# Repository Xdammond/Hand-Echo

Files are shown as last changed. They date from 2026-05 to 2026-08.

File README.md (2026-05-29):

# Hand Echo

## Overview
Hand Echo is a wireless robotic hand teleoperation system designed to replicate user hand movements through a sensor-equipped glove and servo-actuated robotic hand.

## Project Goals
- Capture finger motion using wearable sensors
- Transmit motion data wirelessly between microcontrollers
- Control a robotic hand in real time
- Build a modular system with separate glove, receiver, and mechanical subsystems
- Document hardware, firmware, testing, and lessons learned

## Subsystems

### Glove Controller
The glove controller measures finger movement using sensors mounted to a wearable glove. Sensor data is read by a microcontroller, processed, and prepared for wireless transmission.

### Wireless Communication
The wireless link sends motion data from the glove controller to the robotic hand receiver. This subsystem includes packet formatting, transmission timing, and reliability testing.

### Robotic Hand Receiver
The robotic hand receiver interprets incoming wireless data and controls servos to reproduce finger motion on the robotic hand.

## Repository Structure
docs/          System documentation and engineering notes
hardware/      Schematics, wiring diagrams, and BOMs
firmware/      Microcontroller code
media/         Images, videos, and diagrams
test_data/     Test results and measurements

## Status
Completed

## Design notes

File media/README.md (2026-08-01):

Videos of testing and photos of schematics
This folder contains pictures and videos of testing and schematic design throughout the 14 weeks of testing and troubleshoot

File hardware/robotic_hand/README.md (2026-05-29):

# Robotic Hand

Contains:

- Servo configuration
- Mechanical assembly
- Wiring information

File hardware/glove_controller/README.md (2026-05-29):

# Glove Controller

Contains:

- Sensor information
- Wiring diagrams
- Schematics
- Calibration data

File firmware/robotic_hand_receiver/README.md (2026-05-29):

# Robotic Hand Receiver Firmware

Firmware responsible for:

- Receiving wireless packets
- Mapping data to servos
- Motion control

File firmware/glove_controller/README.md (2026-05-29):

# Glove Controller Firmware

Firmware responsible for:

- Reading sensors
- Processing motion data
- Wireless transmission

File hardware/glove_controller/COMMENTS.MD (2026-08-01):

In file R433A, our original understanding when we first purchased the component was 2 port SAW resonator. As we were testing, we began to see destabilization and oscillation dying. Without a wiring diagram for the part, we asked our professors and they all agreed that it was a two port. We then recreated a two-port system of the Colpitts oscillator but effectively it did not behave like a normal Colpitts Oscillator. It was only till March 15th, 2026, did we discover the true schematic of the component we had and then reworked the circuit back to a one-port design to have stability and ringing. 

The 2N5770 was not the intended BJT nor component we truly wanted to use. But due to our budget, we stuck with the RF BJT because it helped stabilize the circuit and allowed for the proper gain.

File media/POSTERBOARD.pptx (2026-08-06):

## Hand Echo

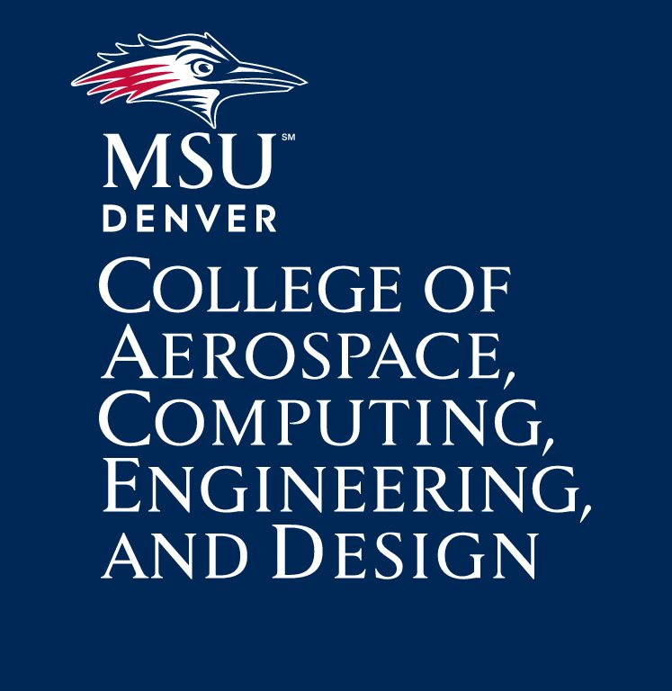
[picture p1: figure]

Student Names: Andres Arcila, John Garcia, Xavier Dammond

Email: arcila.ad23@gmail.com , johngarcia8018@gmail.com , xdammond@gmail.com

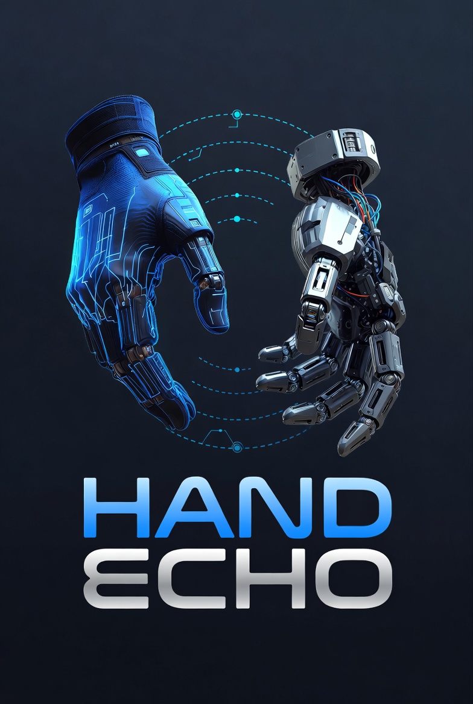
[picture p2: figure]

Conclusion

Advised by: Ke Bao

Email: kbao@msudenver.edu

Intro

Hand Echo is a wireless tele-operation system designed for real-time replication of human hand movements in environments where direct manual interaction is unsafe or impossible. The system integrates a flex-sensor-equipped glove, a custom 433.92 MHz ASK-modulated RF link, and a servo-driven robotic hand to translate finger articulation into precise mechanical motion, enabling safe operation in hazardous settings and supporting prosthetic research and development

Design

Hand Echo is a wireless teleoperation platform engineered to replicate human hand motion on a remote robotic end-effector in real time. Its architecture centers on a two-microcontroller topology — an Arduino Nano on the transmitter side and a Arduino Uno on the receiver side — linked by a 433.92 MHz ASK-modulated RF channel built around a SAW resonator and a custom Colpitts oscillator. Hand Echo integrates five flex sensors arranged in voltage-divider networks and consolidated through a 74HC4051 8-channel multiplexer, producing high-resolution finger-articulation data that is encoded, transmitted over custom-built antennas, and decoded at the receiver. A PCA9685 16-channel PWM driver communicates with the Uno over I²C to drive five servo motors actuating the robotic hand, while onboard firmware maps sensor input to servo position to maintain responsive, low-latency mirroring with minimal operator calibration. Designed for wireless range, modular sensor-to-servo mapping, and reconfigurable control logic, Hand Echo provides a robust foundation for hazardous-environment manipulation and prosthetic research applications.

Materials and methods

Arduino Nano: Microcontroller used on the transmitter (glove) side to read multiplexed flex sensor data and drive the RF transmitter.
Arduino Uno: Microcontroller used on the receiver (hand) side to decode the incoming RF signal and generate servo commands.
Flex Sensors (10 kΩ): Five resistive bend sensors, one per finger, used to measure finger articulation via voltage-divider circuits.
74HC4051 8-Channel Multiplexer: Used to sequentially route all five flex sensor outputs into a single ADC input on the Arduino Nano.
SAW Resonator (433.92 MHz): Surface acoustic wave resonator used as the frequency-reference element for the custom Colpitts oscillator transmitter.
Colpitts Oscillator Transmitter Circuit: Custom-built RF transmitter using ASK (Amplitude Shift Keying) modulation at 433.92 MHz.
RF Receiver Module: Paired 433.92 MHz receiver used to demodulate the ASK signal and forward serial data to the Arduino Uno.
PCA9685 16-Channel PWM Driver: I²C-controlled PWM controller used to generate precise servo signals for all five fingers from the Arduino Uno (SDA on pin 6, SCL on pin 7).
5V Power Supply: Powers the glove-side voltage dividers, multiplexer, and Arduino Nano.
3.7 V Li-Po Battery + 5 V Boost Converter: Portable power supply for the wireless glove assembly.
Robotic Hand with 5 Servo Motors: Mechanical end-effector actuated by the PCA9685 to mirror the operator's finger movements.

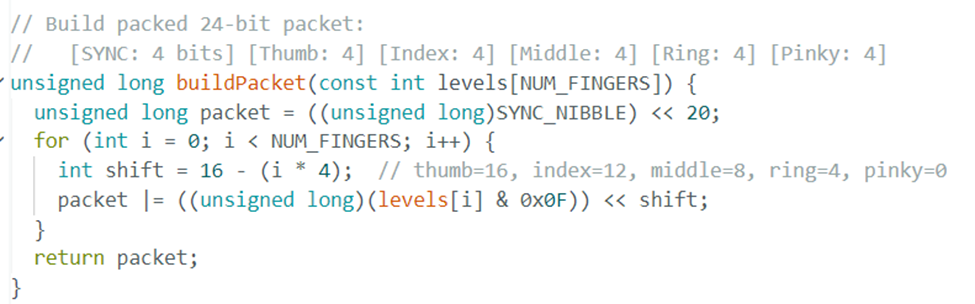
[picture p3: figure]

Results

Hand Echo Systems:

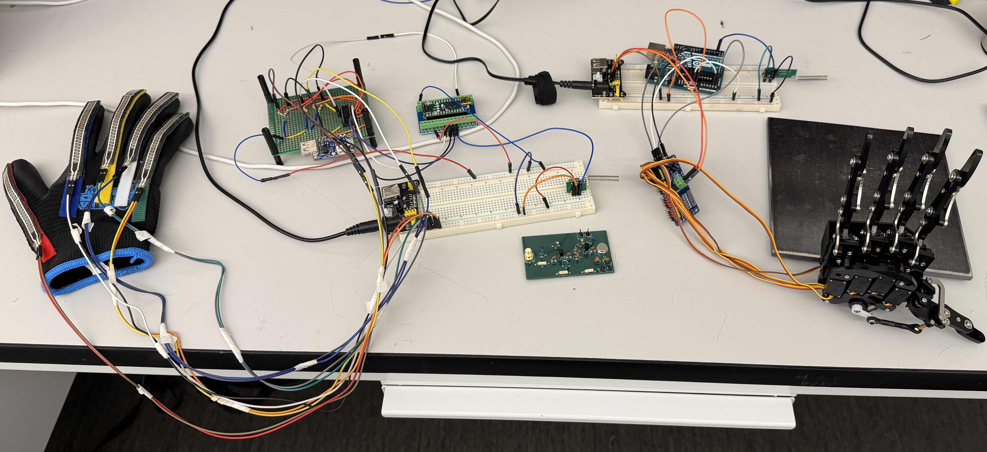
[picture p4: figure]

The Hand Echo wireless teleoperation system successfully demonstrated a functional prototype capable of capturing human finger articulation and mirroring it on a remote robotic hand in real time. Through integrated flex-sensor acquisition, a custom-built 433.92 MHz ASK-modulated RF link, and a PCA9685-driven servo actuator architecture, the system translated operator hand movements into responsive mechanical motion and validated the core design principles of the project. While the prototype met all primary objectives, opportunities remain for refinement and expansion, including resolving the servo snap-back behavior observed during initial testing, improving RF link range and noise immunity, adding bidirectional haptic feedback, expanding the sensor set to capture wrist and individual joint angles, and packaging the glove and hand assemblies into more ergonomic, field-ready enclosures. Overall, Hand Echo provides a strong foundation for a scalable, next-generation platform suited to hazardous-environment manipulation and prosthetic research applications

[1] Pozar, D. M. (2012). Microwave engineering (4th ed.). Wiley.
[2]

Acknowledgements

The group would like to give a special thanks to all of the professors, Lab Coordinators, and student lab assistants at Metropolitan State University of Denver. Without their technical and logistical support and advice this project would not have been possible.

Colpitts Oscillator Transmitter Circuit:

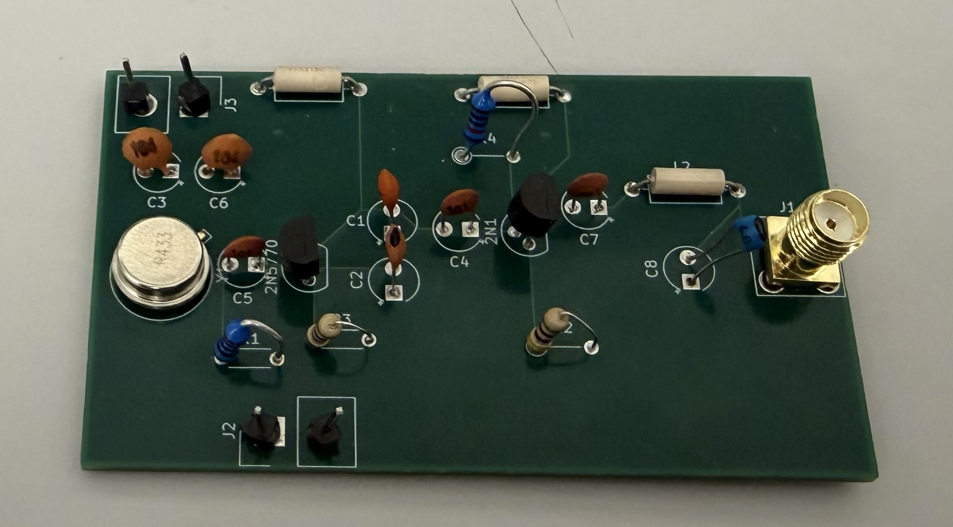
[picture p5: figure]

Code Bit-Packed Protocol

Literature Cited

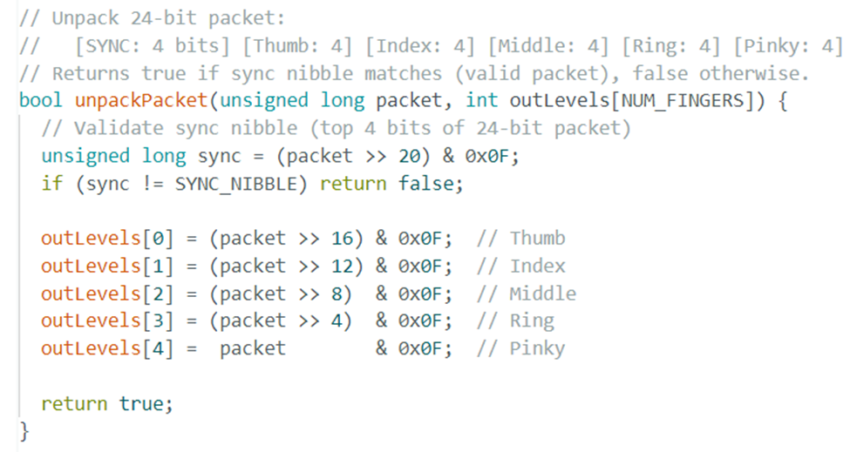
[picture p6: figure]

Waveform

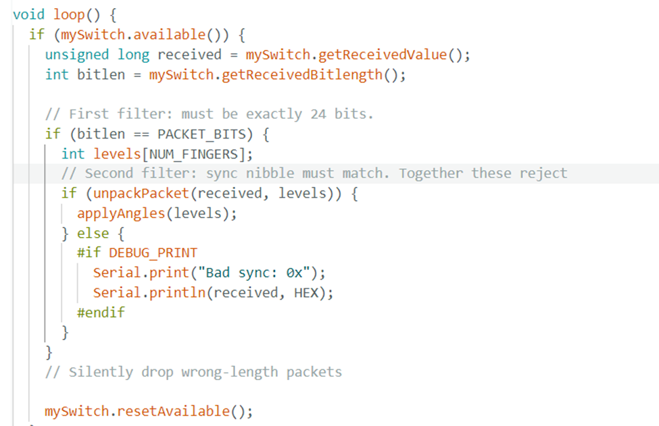
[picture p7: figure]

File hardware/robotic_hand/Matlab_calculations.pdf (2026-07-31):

Contents

John Garcia, Andres Arcilia, Xavier Dammond

%%Senior Project 1

John Garcia, Andres Arcilia, Xavier Dammond

clc; clear;

% ====== Define Average Link Lengths (mm) ======
L1 = 45; % Proximal phalanx: These are the average lengths for a nor %human hand and not our hands.
L2 = 25; % Middle phalanx
L3 = 20; % Distal phalanx
L4 = 15; % Extra flexion for ring/pinky

% ====== Target Fingertip Positions (mm) ====== fingers = {'Thumb','Index','Middle','Ring','Pinky'}; targets = [ 60 20;
70 10;
80 15;
75 5;
65 0];

% ====== Results ======
angle_results = cell(length(fingers), 5);

for i = 1:length(fingers)
finger = fingers{i};
x = targets(i, 1);
y = targets(i, 2);

% Combine L2 + L3 for effective 2R solution Leff1 = L1;
Leff2 = L2 + L3;

% Inverse Kinematics
r2 = x^2 + y^2;
cos_theta2 = (r2 - Leff1^2 - Leff2^2) / (2 * Leff1 * Leff2); cos_theta2 = max(min(cos_theta2, 1), -1); % Clamp to [-1, 1]
theta2 = acos(cos_theta2); | % In radians

k1 = Leff1 + Leff2 * cos(theta2);
k2 = Leff2 * sin(theta2);
theta1 = atan2(y, x) - atan2(k2, k1); | % In radians

% DIP joint estimate (proportional to PIP)
theta3 = theta2 * (20/45); | % Simplified approximation

% Convert to degrees
theta1_deg = rad2deg(theta1);
theta2_deg = rad2deg(theta2);
theta3_deg = rad2deg(theta3);

% For ring and pinky, add a 4th joint estimate
if strcmp(finger, 'Ring') || strcmp(finger, 'Pinky') theta4_deg = 20; % Fixed curl or tendon pull else
theta4_deg = NaN;
end

% Store results
angle_results{i,1} = finger; angle_results{i,2} = round(theta1_deg, 2); angle_results{i,3} = round(theta2_deg, 2); angle_results{i,4} = round(theta3_deg, 2); angle_results{i,5} = round(theta4_deg, 2);
end

% ====== Display Table ======
T = cell2table(angle_results, 'VariableNames', {'Finger','θ1_deg','θ2_deg','θ3_deg','θ4_deg'}); disp(T);
Finger | θ1_deg | θ2_deg | θ3_deg | θ4_deg
__________ | ______ | ______ | ______ | ______
{'Thumb' } | -26.92 | 90.71 | 40.31 | NaN
{'Index' } | -30.09 | 76.43 | 33.97 | NaN
{'Middle'} | -14.64 | 50.52 | 22.45 | NaN
{'Ring' } | -29.55 | 66.73 | 29.66 | 20
{'Pinky' } | -43.76 | 87.52 | 38.9 | 20

Published with MATLAB® R2022b (https://www.mathworks.com/products/matlab/)

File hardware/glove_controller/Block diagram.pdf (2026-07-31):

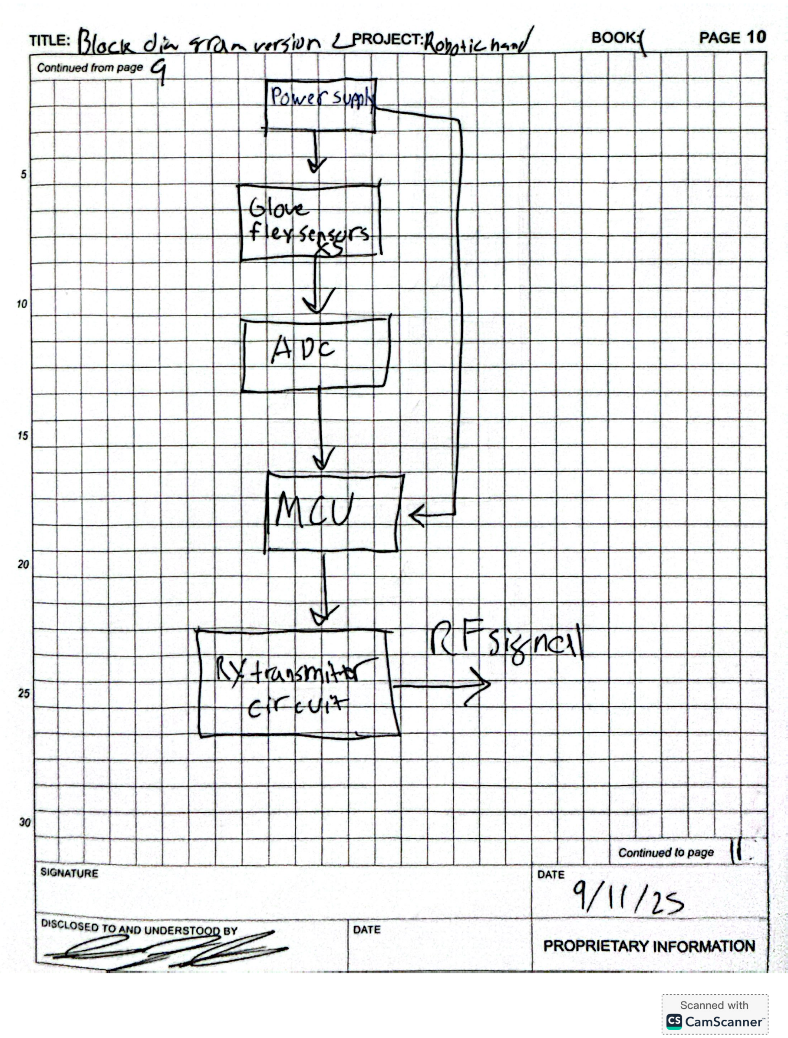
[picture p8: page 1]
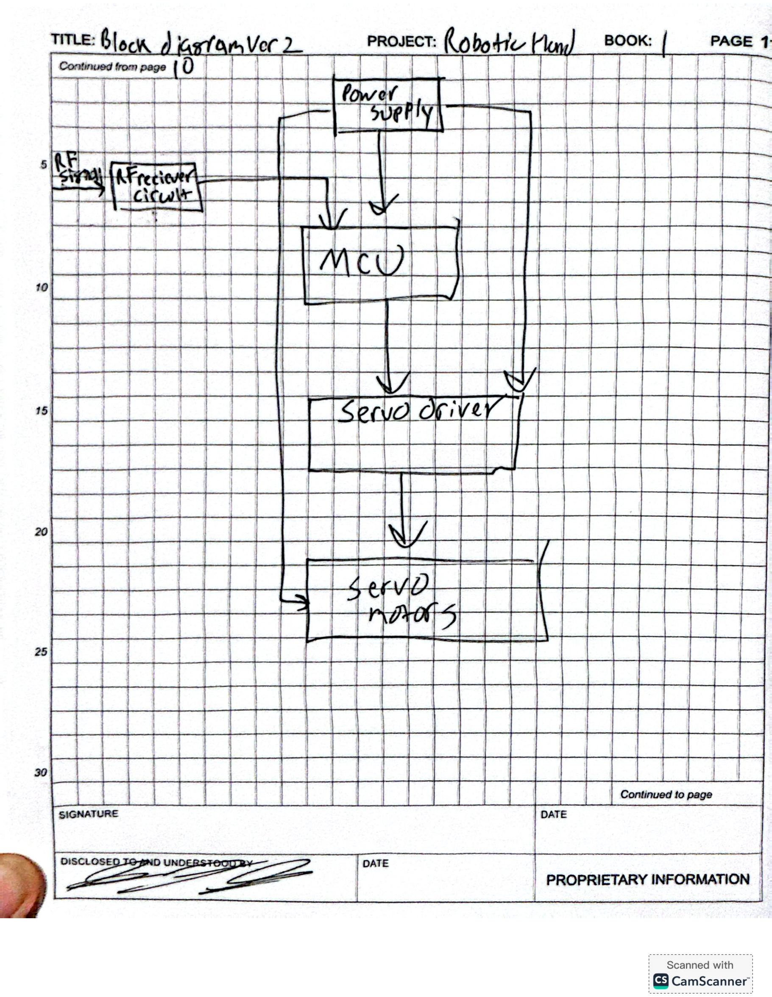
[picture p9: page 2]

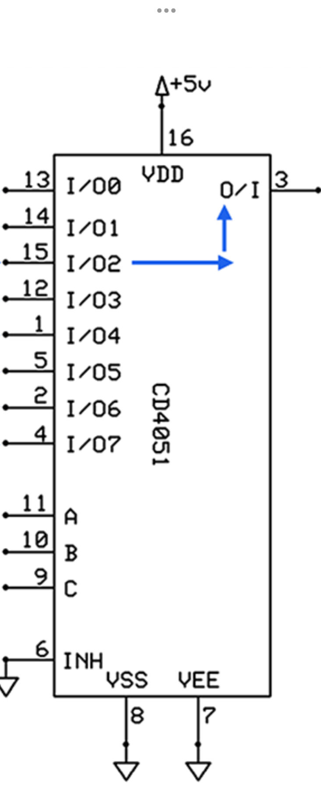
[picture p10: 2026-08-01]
hardware/glove_controller/74HC4051.jpg

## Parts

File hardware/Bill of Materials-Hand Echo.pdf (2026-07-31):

Received | 22
Received | 21
Received | 20
Received | 19
Received | 18
Received | 17
Received | 16
Received | 15
Received | 14
Received | 13
Received | 12
Received | 11
Received | 10
Received | 9
Received | 8
Received | 7
Received | 6
Received | 5
Received | 4
Received | 3 | 5pcs 433mhz Wireless RF Transmitter and Receiver with Antenna Ask Remote Control Module DIY Kit for Arduino
Received | 1
Received | 2 | HiLetgo 2pcs PCA9685 16 Channel 12-Bit PWM Servo Motor Driver IIC Module for Arduino Robot
Status | Find Number

Received
Received

23
24

Not Purchased

Received | 25
Received | 26
Received | 27
Received | 28
Not Purchased | 29
Not Purchased | 30
Not Purchased | 31
Not Purchased | 32
Not Purchased | 33
Not Purchased | 34
Not Purchased | 35
Not Purchased | 36
Not Purchased | 37
Not Purchased | 38

Statuses
Not Purchased
Purchased
Received
Cancelled

22nH Inductor

15pF Capacitor

7.5pF Capacitor

Copper Clad boards

Sma connectors

2n7000-G

100nH Inductors

0.1uH inductors

0.033uH Inductors
0.047uH Inductors

0.27uH Inductors

2N5770

433MHz Transreceiver

7pF Capacitor

68nH Inductor

27nH Inductor

PowerBoost 1000 Charger- Rechargeable 5V Lipo USB Boost @1A-1000c

Lithium Ion Polymer battery-3.7V 500mAh

Arduino Nano

5pcs 433mhz Wireless RF Transmitter and Receiver with Antenna Ask Remote Control Module DIY Kit for Arduino

Robot Hand Five Fingers Solely Movement Bionic Robot Mechanical Arm DIY, Right Hand

HiLetgo 2pcs PCA9685 16 Channel 12-Bit PWM Servo Motor Driver IIC Module for Arduino Robot

# Purchase Requests

Description

# Hand Echo

33k ohm chip resistor
100k ohm chip resistor

100pF capacitor
100nF capacitor

22pF capacitor

150 ohm chip resistor

$0.09 | 25 | $2.20 (https://www.mouser.com/ProductDetail/Murata-Electronics/LQW2BAS27NJ00L?qs=XY81OjNnpanytpCHSD7Xvg%3D%3D) | Mouser (https://www.mouser.com/ProductDetail/Murata-Electronics/LQW2BAS27NJ00L?qs=XY81OjNnpanytpCHSD7Xvg%3D%3D)
$0.19 | 25 | $4.83 | Mouser (https://www.mouser.com/ProductDetail/Murata-Electronics/LQW15AW68NG80D?qs=B6kkDfuK7%2FDzrzt3MYe9Zg%3D%3D)
$0.28 | 5 | $1.40 | Newark (https://www.newark.com/tdk/fg28c0g2a070dnt00/cap-7pf-100v-mlcc-radial-rohs/dp/70AK2660)
$9.99 | 1 | $9.99 | Amazon
$0.31 | 10 | $3.10 | DigiKey (https://www.digikey.com/en/products/detail/central-semiconductor-corp/2N5770-PBFREE/4806922)
$3.79 | 10 | $37.90 | DigiKey
$3.03 | 5 | $15.15 | DigiKey
$3.79 | 5 | $18.95 | DigiKey
$0.26 | 5 | $1.30 | DigiKey
$1.05 | 5 | $5.25 | DigiKey
$0.50 | 10 | $5.00 | DigiKey
$10.99 | 1 | $10.99 | amazon (https://www.amazon.com/bnafes-Straight-Connector-Coaxial-Adapter/dp/B09N1RBBFX)
$6.99 | 1 | $6.99 | amazon
$0.08 | 10 | $0.80 | Digikey (https://www.digikey.com/en/products/detail/murata-electronics/GJM1555C1H7R5WB01D/2593133)
$0.07 | 10 | $0.65 | Digikey (https://www.digikey.com/en/products/detail/murata-electronics/GJM1555C1H150GB01D/2592856)
$0.12 | 10 | $1.24 | DigiKey (https://www.digikey.com/en/products/detail/murata-electronics/LQW2BASR22J00L/2625454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)
$0.00 | 10 | $0.04 | DigiKey (https://www.digikey.com/en/products/detail/yageo/RC0402FR-0733KL/726592)
$0.00 | 10 | $0.04 | DigiKey (https://www.digikey.com/en/products/detail/yageo/RC0402FR-07100KL/726526)
| | | Adafruit | https://www.adafruit.com/product/1578
$19.95 | 1 | $19.95 | Adafruit | https://www.adafruit.com/product/2465
$99.00 | 1 | $99.00 | Amazon
$13.00 | 1 | $13.00 | Amazon (https://www.amazon.com/HiLetgo-PCA9685-Channel-12-Bit-Arduino/dp/B07BRS249H)
$9.99 | 1 | $9.99 (https://www.amazon.com/D-FLIFE-Wireless-Transmitter-Receiver-Antenna/dp/B0BZRRBBNK) | Amazon (https://www.amazon.com/D-FLIFE-Wireless-Transmitter-Receiver-Antenna/dp/B0BZRRBBNK)
$24.99 | 1 | $24.99 | Amazon (https://www.amazon.com/Arduino-A000005-ARDUINO-Nano/dp/B0097AU5OU?sp_csd=d2lkZ2V0TmFtZT1zcF9hdGY)
$7.95 | 1 | $7.95

Movement-Bionic-Mechanical-DIY%EF%BC%88Right/dp/B081RR42 (https://www.amazon.com/Fingers-Movement-Bionic-Mechanical-DIY%EF%BC%88Right/dp/B081RR4224?th=1)

# Purchase Requests

Unit Cost | Quanity | Cost | Supplier | Where to Buy Links

# Hand Echo

Total | 204 | $303.92
$0.20 | 10 | $2.00 | DigiKey (https://www.digikey.com/en/products/detail/yageo/RC0402FR-07150RL/726543)
$0.07 | 10 | $0.69 | DigiKey (https://www.digikey.com/en/products/detail/murata-electronics/GJM1555C1H220FB01D/7362929)
$0.01 | 10 | $0.14 | DigiKey (https://www.digikey.com/en/products/detail/murata-electronics/GRM1885C1H101JA01D/586921)
$0.04 | 10 | $0.39 | DigiKey (https://www.digikey.com/en/products/detail/samsung-electro-mechanics/CL05B104KP5VPNC/20498482)

Movement-Bionic-Mechanical-

Where to Buy Links

| Approvals
POC | Teammate

24?th=1

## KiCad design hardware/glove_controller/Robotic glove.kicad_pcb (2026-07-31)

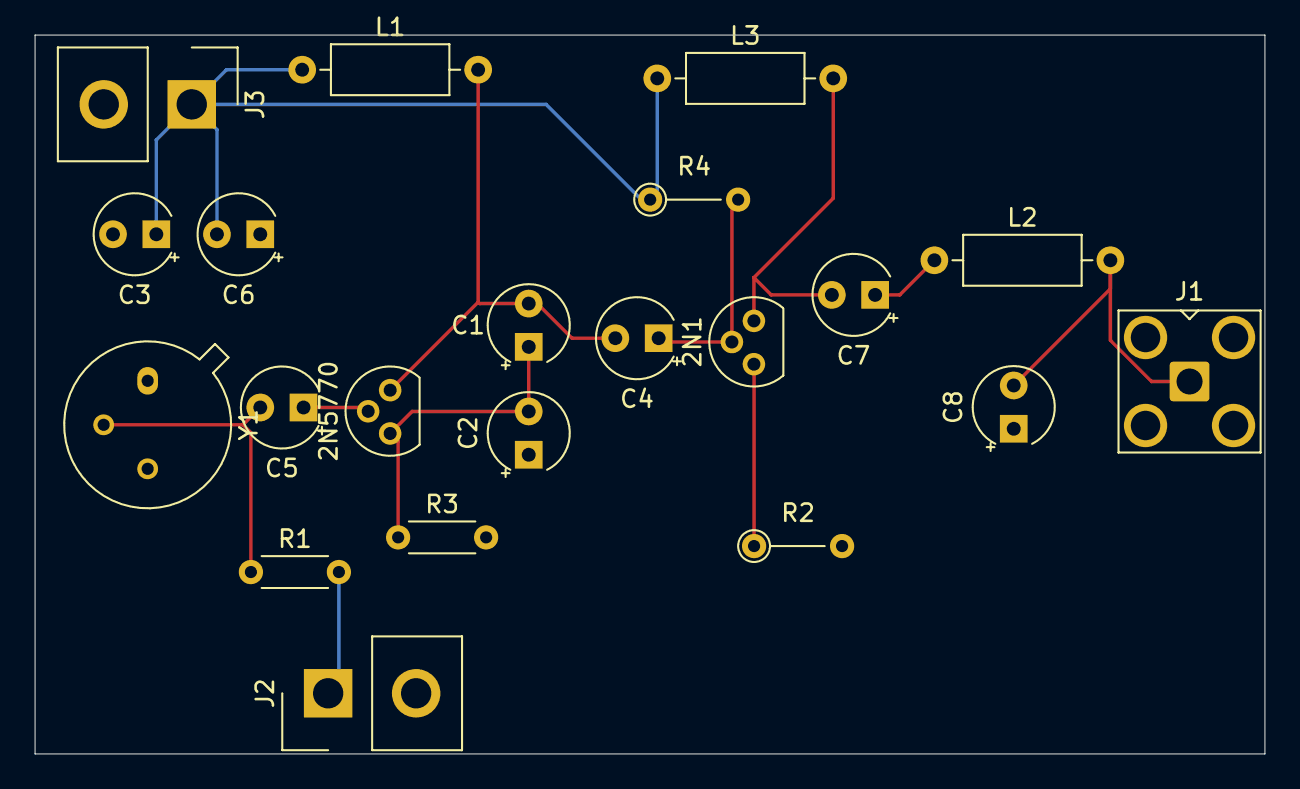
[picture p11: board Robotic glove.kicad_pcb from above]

Board: 4 copper layers, 71.0 x 41.5 mm, 21 parts (0 on the bottom side), 12 nets.

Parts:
2N1, 2N5770: Q_NPN_CBE; TO-92L
C1: 7.5pF; CP_Radial_Tantal_D4.5mm_P2.50mm
C2: 15pF; CP_Radial_Tantal_D4.5mm_P2.50mm
C3, C6: 100nF; CP_Radial_Tantal_D4.5mm_P2.50mm
C4: 10pF; CP_Radial_Tantal_D4.5mm_P2.50mm
C5, C7: 100pF; CP_Radial_Tantal_D4.5mm_P2.50mm
C8: 22pF; CP_Radial_Tantal_D4.5mm_P2.50mm
J1: 132134-15; SMA_Amphenol_901-143_Horizontal
J2, J3: Conn_01x02; Samtec_HPM-02-05-x-S_Straight_1x02_Pitch5.08mm
L1, L3: 27nH; L_Axial_L6.6mm_D2.7mm_P10.16mm_Horizontal_Vishay_IM-2
L2: 23nH; L_Axial_L6.6mm_D2.7mm_P10.16mm_Horizontal_Vishay_IM-2
R1: 33k; R_Axial_DIN0204_L3.6mm_D1.6mm_P5.08mm_Horizontal
R2, R4: 100; R_Axial_DIN0204_L3.6mm_D1.6mm_P5.08mm_Vertical
R3: 68; R_Axial_DIN0204_L3.6mm_D1.6mm_P5.08mm_Horizontal
Y1: Crystal_GND3; TO-39-3

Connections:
+5V: C3.1, C6.2, J3.1, L1.1, L3.1, R4.1
/Arduino TX in: J2.1, R1.2
Earth: C2.1, C3.2, C6.1, C8.1, J1.2, J2.2, J3.2, R2.2, R3.2, Y1.1, Y1.3
unnamed: 2N1.2 (B), C4.1, R4.2
unnamed: 2N1.1 (C), C7.2, L3.2
unnamed: 2N1.3 (E), R2.1
unnamed: 2N5770.2 (B), C5.1
unnamed: 2N5770.1 (C), C1.2, C4.2, L1.2
unnamed: 2N5770.3 (E), C1.1, C2.2, R3.1
unnamed: C5.2, R1.1, Y1.2
unnamed: C7.1, L2.1
unnamed: C8.2, J1.1, L2.2

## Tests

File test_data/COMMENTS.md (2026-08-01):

Our first test of the circuit came from analyzing an oscilloscope signal we had obtained. At first, we wondered why there was no oscillation and figured our circuit design was bad. As we moved through the weeks, it came to our attention that oscilloscope we were working with did not read up 400MHz and was effectively capped at 150MHz for a reading. We also discovered that using a bread board at 200MHz and above causes distortion inside the signal making what we were testing incorrect and data invaluable.

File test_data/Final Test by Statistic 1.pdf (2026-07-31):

## Final Test by Statistic

By: Andres Arcilia, Xavier Dammond, John Garcia

Introduction

The final test by statistics will measure 1’s and 0’s and voltage based on the keying of the transmitter of the flex sensors and the signal transmitted to the receiver module and is decoded.

Measurements/Calculations

Trial | TX volt | RX Volt
1 | 5V | 0V
2 | 3.3V | 0V
3 | 0V | 0V
4 | 5V | 3.3V
5 | 4.2V | 3.3V
6 | 5V | 5V
7 | 3.3V | 1.7V
8 | 0V | 0V
9 | 4.2V | 0V
10 | 0V | 0V
Mean TX | 3.25V
Range TX | 5V
Std Dev TX | 2.07V
Mean RX | 1.33V
Range RX | 5V
Std Dev RX | 1.789V

Analysis and Conclusion

Analysis of the TX and RX voltage data reveals that there is a decoding reliability issue within the receiver module. Even though the transmitter was able to consistently output the expected voltage levels in response to the flex sensor inputs, the receiver module failed to mirror the values within the same consistency. This could point to bit drop errors during signal decoding, which could be caused by timing mismatch, protocol not engaging properly or insufficient signal strength.

0

1

2

3

4

5

6

1 | 2 | 3 | 4 | 5 | 6 | 7 | 8 | 9 | 10

TX VS RX Voltage

TX Volts RX Volts

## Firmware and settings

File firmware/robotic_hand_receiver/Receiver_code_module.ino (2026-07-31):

/*
 * Wireless Robotic Glove - RECEIVER
 * Arduino Uno + PCA9685 + 5x LFD-01 Servos
 *
 * Protocol: 24-bit packet, bit-packed (matches transmitter exactly)
 *   [SYNC: 4 bits = 0xA] [Thumb: 4] [Index: 4] [Middle: 4] [Ring: 4] [Pinky: 4]
 *   Each finger: 0-15 (16 levels)
 *   Sync nibble validation rejects ~94% of random noise.
 *
 * Wiring:
 * --- 433MHz Receiver ---
 * DATA -> D2 (interrupt 0)
 * VCC  -> 5V
 * GND  -> GND
 *   17.3cm antenna wire on RX module ANT pad
 *
 * --- PCA9685 (I2C) ---
 * VCC -> 5V, GND -> GND, SDA -> A4, SCL -> A5
 * V+  -> External 5V (servo power, separate from logic if possible)
 *
 * --- Servos on PCA9685 ---
 * CH0 -> Thumb, CH1 -> Index, CH2 -> Middle, CH3 -> Ring, CH4 -> Pinky
 */

#include <RCSwitch.h>
#include <Wire.h>
#include <Adafruit_PWMServoDriver.h>

RCSwitch mySwitch = RCSwitch();
Adafruit_PWMServoDriver pca = Adafruit_PWMServoDriver(0x40);

// --- Servo timing ---
// 600-2400us avoids hitting hard stops on most hobby servos. Wider ranges
// cause stall current and supply noise that can deafen the 433MHz receiver.
#define SERVO_MIN_PULSE  600
#define SERVO_MAX_PULSE  2400
#define PCA_FREQ         50

// --- Protocol (must match transmitter exactly) ---
#define NUM_FINGERS       5
#define PACKET_BITS       24
#define SYNC_NIBBLE       0xA
#define LEVELS_PER_FINGER 16
#define MAX_LEVEL         15

// --- Smoothing ---
#define SMOOTH_FACTOR    0.40f

// Precomputed PWM tick conversion: at 50Hz, 4096 ticks per 20000us period.
// tick = (us * 4096 * PCA_FREQ) / 1,000,000 — pure integer math.
#define US_TO_TICK(us)   ((int)(((long)(us) * 4096L * PCA_FREQ) / 1000000L))

const int servoChannel[NUM_FINGERS] = { 0, 1, 2, 3, 4 };

const char* fingerName[NUM_FINGERS] = {
  "Thumb", "Index", "Middle", "Ring", "Pinky"
};

// Mechanical inversion: thumb is mounted opposite the other fingers in this
// hand assembly, so its servo direction is not inverted while the other four
// are. Update this array if you swap or remount any servos.
const bool invertFinger[NUM_FINGERS] = {
  false,  // Thumb
  true,   // Index
  true,   // Middle
  true,   // Ring
  true    // Pinky
};

float smoothedAngle[NUM_FINGERS] = { 0, 0, 0, 0, 0 };
bool firstPacket = true;

#define DEBUG_PRINT 1

void setServoAngle(int channel, int angle) {
  angle = constrain(angle, 0, 180);
  int pulseUs = map(angle, 0, 180, SERVO_MIN_PULSE, SERVO_MAX_PULSE);
  pca.setPWM(channel, 0, US_TO_TICK(pulseUs));
}

// Unpack 24-bit packet:
//   [SYNC: 4 bits] [Thumb: 4] [Index: 4] [Middle: 4] [Ring: 4] [Pinky: 4]
// Returns true if sync nibble matches (valid packet), false otherwise.
bool unpackPacket(unsigned long packet, int outLevels[NUM_FINGERS]) {
  // Validate sync nibble (top 4 bits of 24-bit packet)
  unsigned long sync = (packet >> 20) & 0x0F;
  if (sync != SYNC_NIBBLE) return false;

  outLevels[0] = (packet >> 16) & 0x0F;  // Thumb
  outLevels[1] = (packet >> 12) & 0x0F;  // Index
  outLevels[2] = (packet >> 8)  & 0x0F;  // Middle
  outLevels[3] = (packet >> 4)  & 0x0F;  // Ring
  outLevels[4] =  packet        & 0x0F;  // Pinky

  return true;
}

void applyAngles(const int levels[NUM_FINGERS]) {
  #if DEBUG_PRINT
    Serial.print("OK | ");
  #endif

  for (int i = 0; i < NUM_FINGERS; i++) {
    int angle = map(levels[i], 0, MAX_LEVEL, 0, 180);
    if (invertFinger[i]) angle = 180 - angle;

    if (firstPacket) {
      smoothedAngle[i] = angle;
    } else {
      smoothedAngle[i] = (SMOOTH_FACTOR * angle) +
                         ((1.0f - SMOOTH_FACTOR) * smoothedAngle[i]);
    }

    int finalAngle = (int)smoothedAngle[i];
    setServoAngle(servoChannel[i], finalAngle);

    #if DEBUG_PRINT
      Serial.print(fingerName[i]);
      Serial.print(":");
      Serial.print(finalAngle);
      Serial.print(" ");
    #endif
  }
  firstPacket = false;

  #if DEBUG_PRINT
    Serial.println();
  #endif
}

void startupSequence() {
  Serial.println("Step 1: Closing hand...");
  for (int angle = 0; angle <= 180; angle++) {
    for (int i = 0; i < NUM_FINGERS; i++) {
      int a = invertFinger[i] ? (180 - angle) : angle;
      setServoAngle(servoChannel[i], a);
    }
    delay(20);
  }
  delay(500);

  Serial.println("Step 2: Opening hand...");
  for (int angle = 180; angle >= 0; angle--) {
    for (int i = 0; i < NUM_FINGERS; i++) {
      int a = invertFinger[i] ? (180 - angle) : angle;
      setServoAngle(servoChannel[i], a);
    }
    delay(20);
  }
  delay(500);

  Serial.println("Startup complete - now receiving data...");
  Serial.println("=================================");
}

void setup() {
  Serial.begin(115200);

  pca.begin();
  pca.setOscillatorFrequency(27000000);
  pca.setPWMFreq(PCA_FREQ);
  delay(100);

  Serial.println("=================================");
  Serial.println("Robotic Glove - Receiver");
  Serial.println("   24-bit packed, sync 0xA");
  Serial.println("=================================");

  startupSequence();

  // Enable RF receive after startup so servo PWM transients during the
  // calibration sweep don't get misread as data on the interrupt pin.
  mySwitch.enableReceive(0);  // interrupt 0 = D2 on Uno
}

void loop() {
  if (mySwitch.available()) {
    unsigned long received = mySwitch.getReceivedValue();
    int bitlen = mySwitch.getReceivedBitlength();

    // First filter: must be exactly 24 bits.
    if (bitlen == PACKET_BITS) {
      int levels[NUM_FINGERS];
      // Second filter: sync nibble must match. Together these reject
      // virtually all noise-induced false decodes.
      if (unpackPacket(received, levels)) {
        applyAngles(levels);
      } else {
        #if DEBUG_PRINT
          Serial.print("Bad sync: 0x");
          Serial.println(received, HEX);
        #endif
      }
    }
    // Silently drop wrong-length packets — they're almost always noise.

    mySwitch.resetAvailable();
  }
}

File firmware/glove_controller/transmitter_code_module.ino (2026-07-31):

/*
 * Wireless Robotic Glove - TRANSMITTER
 * Arduino Nano + 74HC4051 mux + 5x flex sensors
 *
 * Protocol: 24-bit packet, bit-packed
 *   [SYNC: 4 bits = 0xA] [Thumb: 4] [Index: 4] [Middle: 4] [Ring: 4] [Pinky: 4]
 *   Each finger: 0-15 (16 levels, ~12 deg per step)
 *   Sync nibble 0xA rejects ~94% of random noise on receiver side.
 *
 * Wiring:
 * --- 74HC4051 Multiplexer ---
 * VCC -> 5V, GND -> GND, VEE -> GND, E -> GND
 * COM/OUT -> A0, S0 -> D4, S1 -> D5, S2 -> D6
 *
 * --- Flex Sensors ---
 * Thumb -> Y0, Index -> Y1, Middle -> Y2, Ring -> Y3, Pinky -> Y4
 *   (one end 5V, other end Y# + 47kohm to GND)
 *
 * --- 433MHz Transmitter ---
 * DATA -> D7, VCC -> 5V, GND -> GND
 *   17.3cm antenna wire on TX module ANT pad
 */

#include <RCSwitch.h>

RCSwitch mySwitch = RCSwitch();

// --- Pins ---
#define MUX_S0   4
#define MUX_S1   5
#define MUX_S2   6
#define MUX_COM  A0
#define TX_PIN   7

// --- Sampling ---
#define NUM_SAMPLES   3
#define NUM_FINGERS   5

// --- Protocol (must match receiver exactly) ---
#define PACKET_BITS       24
#define SYNC_NIBBLE       0xA
#define LEVELS_PER_FINGER 16
#define MAX_LEVEL         15

// --- Transmission policy ---
#define CHANGE_THRESH_LEVELS  1     // re-send if any finger changes >= 1 level
#define HEARTBEAT_MS          250   // re-send every 250ms even with no change
#define LOOP_DELAY_MS         5     // ~30Hz upper bound (limited by RCSwitch send time)

const int muxChannel[NUM_FINGERS] = { 0, 1, 2, 3, 4 };
const char* fingerName[NUM_FINGERS] = {
  "Thumb", "Index", "Middle", "Ring", "Pinky"
};

// Per-finger calibration. Replace with values from a calibration routine
// (hand flat = straight, full fist = bent). 80/1020 are placeholders.
int flexStraight[NUM_FINGERS] = {  80,  80,  80,  80,  80 };
int flexBent[NUM_FINGERS]     = { 1020, 1020, 1020, 1020, 1020 };

int lastLevelSent[NUM_FINGERS] = { -1, -1, -1, -1, -1 };
unsigned long lastTxTime = 0;

#define DEBUG_PRINT 1

void selectMuxChannel(int channel) {
  digitalWrite(MUX_S0, (channel & 0x01) ? HIGH : LOW);
  digitalWrite(MUX_S1, (channel & 0x02) ? HIGH : LOW);
  digitalWrite(MUX_S2, (channel & 0x04) ? HIGH : LOW);
}

int readFlexSmoothed(int channel) {
  // Switch mux ONCE, then take samples. Don't switch per sample.
  selectMuxChannel(channel);
  delayMicroseconds(150);
  analogRead(MUX_COM);  // dummy read for ADC sample-and-hold settle

  long total = 0;
  for (int i = 0; i < NUM_SAMPLES; i++) {
    total += analogRead(MUX_COM);
  }
  return (int)(total / NUM_SAMPLES);
}

// Build packed 24-bit packet:
//   [SYNC: 4 bits] [Thumb: 4] [Index: 4] [Middle: 4] [Ring: 4] [Pinky: 4]
unsigned long buildPacket(const int levels[NUM_FINGERS]) {
  unsigned long packet = ((unsigned long)SYNC_NIBBLE) << 20;
  for (int i = 0; i < NUM_FINGERS; i++) {
    int shift = 16 - (i * 4);  // thumb=16, index=12, middle=8, ring=4, pinky=0
    packet |= ((unsigned long)(levels[i] & 0x0F)) << shift;
  }
  return packet;
}

void setup() {
  Serial.begin(115200);

  pinMode(MUX_S0, OUTPUT);
  pinMode(MUX_S1, OUTPUT);
  pinMode(MUX_S2, OUTPUT);
  digitalWrite(MUX_S0, LOW);
  digitalWrite(MUX_S1, LOW);
  digitalWrite(MUX_S2, LOW);

  mySwitch.enableTransmit(TX_PIN);
  mySwitch.setProtocol(1);
  mySwitch.setPulseLength(350);
  mySwitch.setRepeatTransmit(3);  // 3 repeats balances reliability vs. throughput

  Serial.println("=================================");
  Serial.println("Robotic Glove - Transmitter");
  Serial.println("   24-bit packed, sync 0xA");
  Serial.println("=================================");
}

void loop() {
  int currentLevels[NUM_FINGERS];
  bool anyChanged = false;

  // Read all five fingers in one synchronized snapshot — every transmitted
  // packet then represents one consistent moment of hand state.
  for (int i = 0; i < NUM_FINGERS; i++) {
    int raw = readFlexSmoothed(muxChannel[i]);
    int angle = map(raw, flexStraight[i], flexBent[i], 0, 180);
    angle = constrain(angle, 0, 180);

    int level = map(angle, 0, 180, 0, MAX_LEVEL);
    level = constrain(level, 0, MAX_LEVEL);

    currentLevels[i] = level;
    if (abs(level - lastLevelSent[i]) >= CHANGE_THRESH_LEVELS) {
      anyChanged = true;
    }
  }

  unsigned long now = millis();
  bool heartbeatDue = (now - lastTxTime) >= HEARTBEAT_MS;

  if (anyChanged || heartbeatDue) {
    unsigned long packet = buildPacket(currentLevels);
    mySwitch.send(packet, PACKET_BITS);
    lastTxTime = now;
    for (int i = 0; i < NUM_FINGERS; i++) lastLevelSent[i] = currentLevels[i];

    #if DEBUG_PRINT
      Serial.print(anyChanged ? "TX " : "HB ");
      Serial.print("0x");
      Serial.print(packet, HEX);
      Serial.print(" | ");
      for (int i = 0; i < NUM_FINGERS; i++) {
        Serial.print(fingerName[i]);
        Serial.print(":");
        Serial.print(currentLevels[i]);
        Serial.print(" ");
      }
      Serial.println();
    #endif
  }

  delay(LOOP_DELAY_MS);
}

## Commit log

2026-08-01 Fix typo and add description to README
    This folder contains pictures and videos of testing and schematic design throughout the 14 weeks of testing and troubleshooting.
2026-08-01 Update COMMENTS.MD with component testing insights
    Added detailed comments regarding the testing and circuit design changes for the R433A component and the use of the 2N5770 BJT.
2026-08-01 Add initial test observations to COMMENTS.md
    Documented initial test results and observations regarding circuit performance and oscilloscope limitations.
2026-08-01 Add files via upload
    The 74HC4051 was used to the Arduino Nano to take in multiple sensor readings at one time. While the Nano can do this itself, we were having issues without the Multiplexer and figured it would be best to leave it in.
2026-08-01 Add files via upload
    This is the Bill of Material for Hand Echo. There were some out of pocket expenses not covered in this document due to budget constraints and the time of need for these components.
